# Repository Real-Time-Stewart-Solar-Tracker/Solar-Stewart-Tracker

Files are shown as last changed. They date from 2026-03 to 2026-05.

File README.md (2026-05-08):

# SunLock Lab Solar Stewart Tracker

<p align="center">
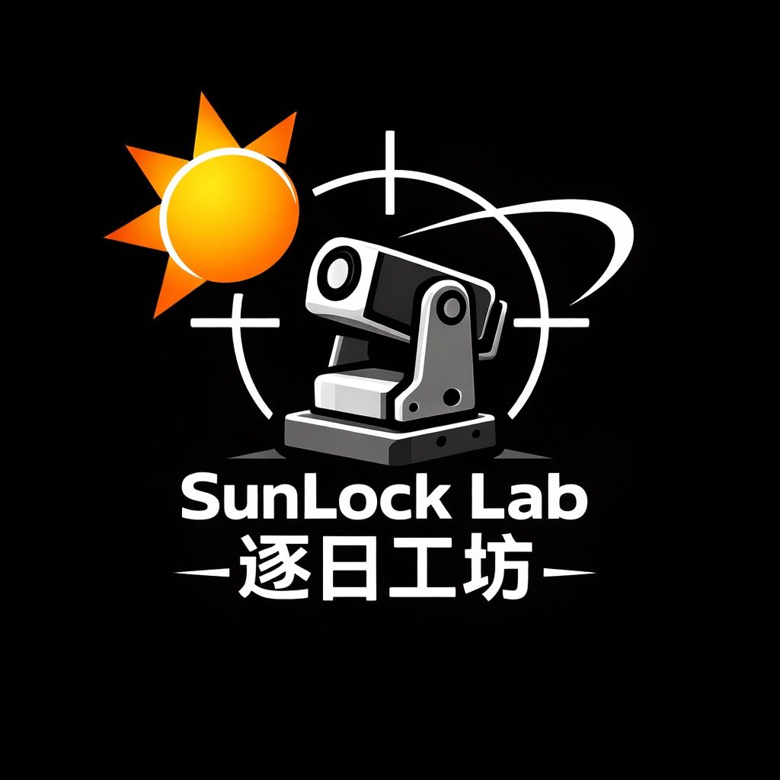
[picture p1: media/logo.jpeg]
SunLock Lab Solar Stewart Tracker
  
</p>





Real-time embedded **C++17** software for solar tracking using a **3-RRS Stewart-type parallel mechanism** on **Raspberry Pi / Linux**.

This project implements an event-driven pipeline in which camera frames are delivered through callbacks, processed by vision and control modules, converted into platform motion through inverse kinematics, and safely applied to three actuators through a hardware abstraction layer. The runtime is structured around blocking waits, callback-driven stage transitions, bounded queues, and modular components so the software remains responsive, maintainable, testable, and reproducible.

<p align="center">
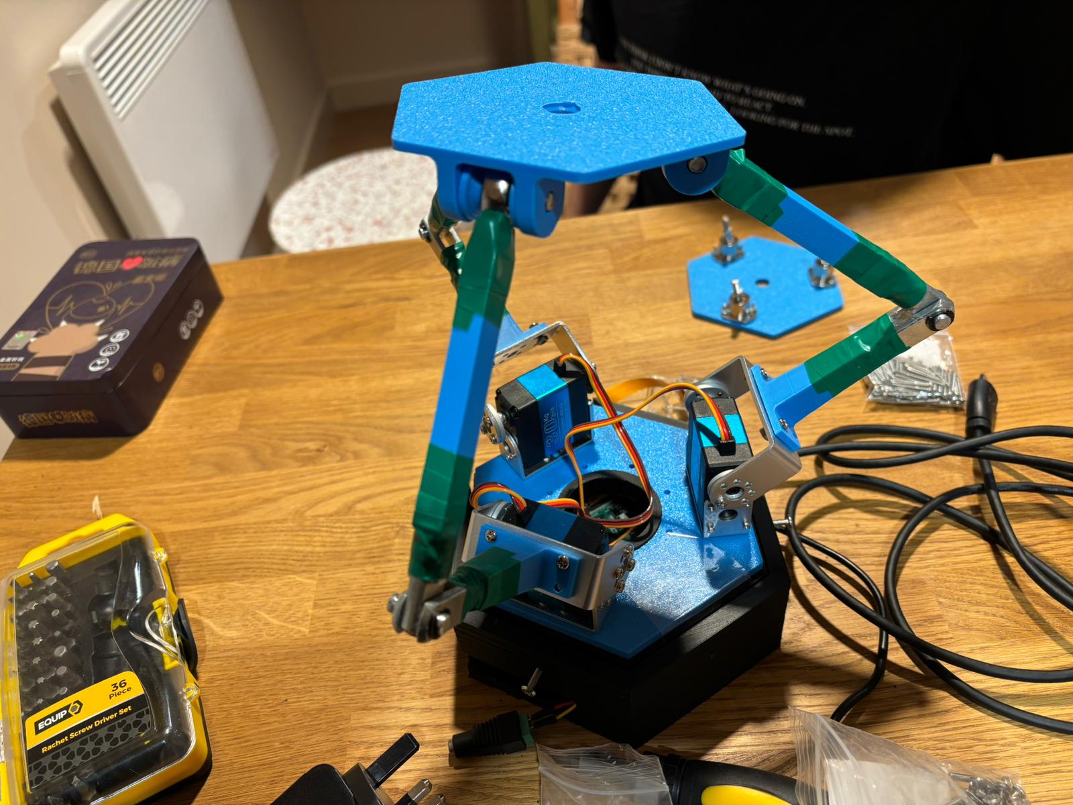
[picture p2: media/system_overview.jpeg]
System Overview
  
</p>
<p align="center">
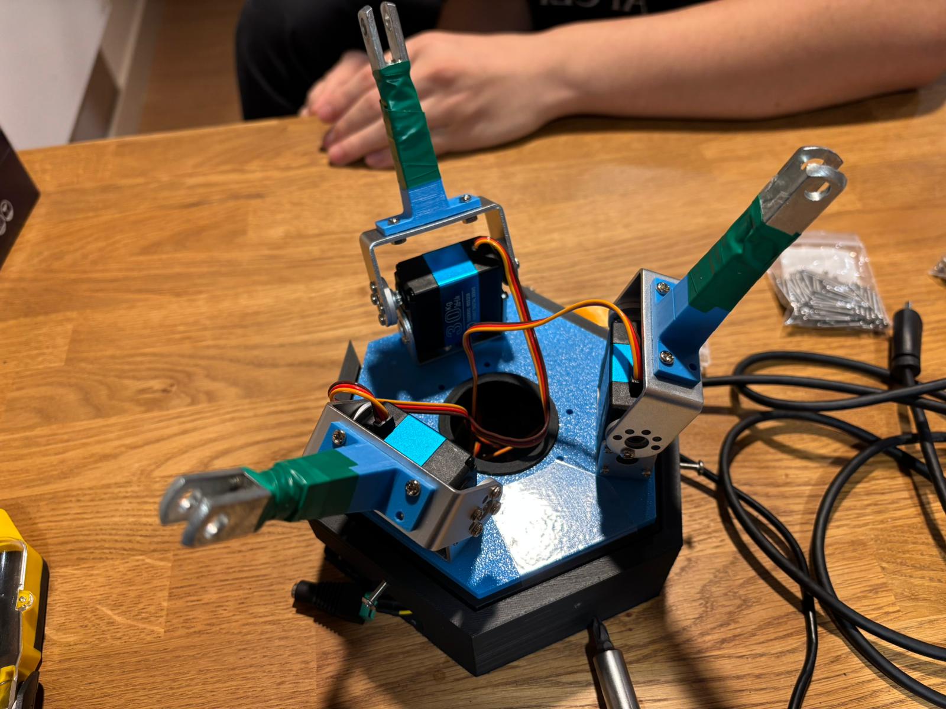
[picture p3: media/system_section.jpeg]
System Section
  
</p>
<p align="center">
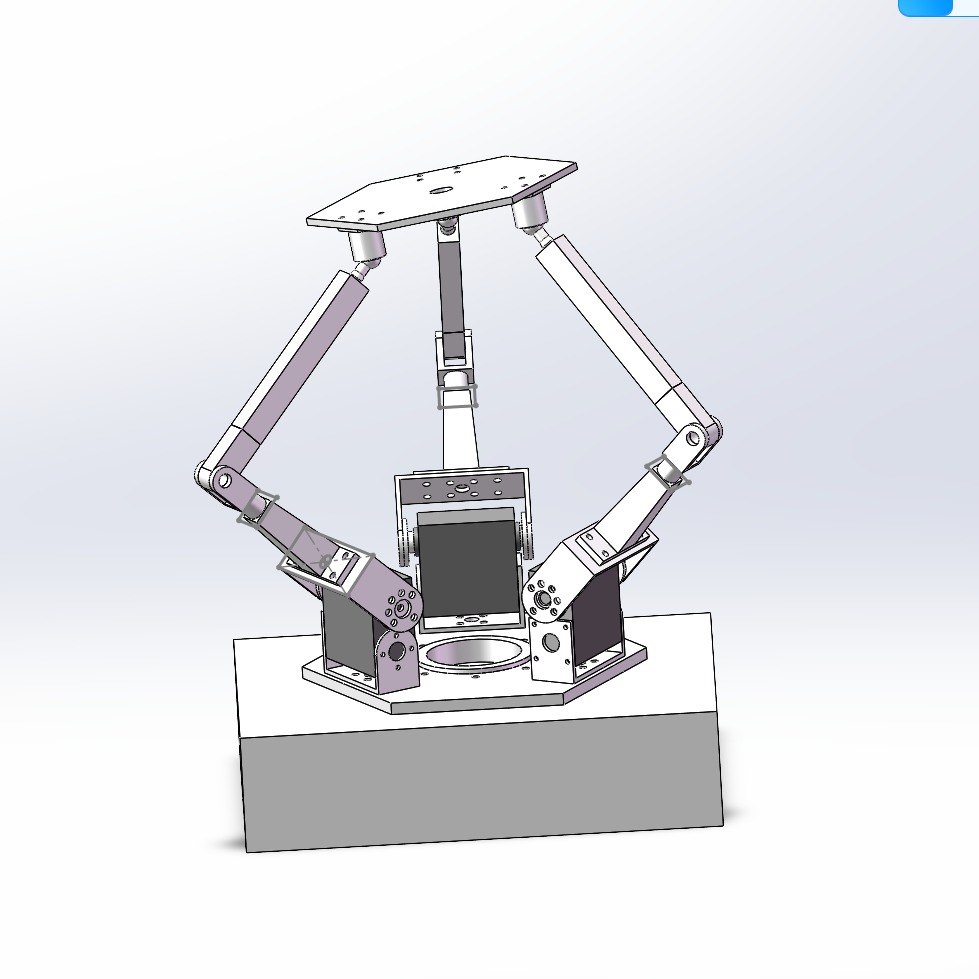
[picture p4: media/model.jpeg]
System Model
  
</p>

### Demo

A short demonstration of the tracker running on hardware is available in the repository root:
https://www.youtube.com/shorts/J-tgFS92vjE
[`Demo Solar Tracker.mp4`](Demo%20Solar%20Tracker.mp4)

---

<p align="center">
  <strong>Explore the full generated developer reference, architecture pages, and API documentation.</strong><br>
  📘 <a href="https://real-time-stewart-solar-tracker.github.io/Solar-Stewart-Tracker/">
    Doxygen Documentation
  </a>
</p>

---

## Table of Contents

- [Social Media](#social-media)
- [Project Overview](#project-overview)
- [Project Management](#project-management)
- [Key Features](#key-features)
- [System Architecture](#system-architecture)
- [Threading and Event Model](#threading-and-event-model)
- [Sequence Diagram](#sequence-diagram)
- [Circuit Diagram](#circuit-diagram)
- [Repository Structure](#repository-structure)
- [Bill of Materials](#bill-of-materials)
- [Dependencies](#dependencies)
- [Cloning](#cloning)
- [Building](#building)
- [Running](#running)
- [Running Tests](#running-tests)
- [Realtime Evidence](#realtime-evidence)
- [Documentation](#documentation)
- [Authors and Contributions](#authors-and-contributions)
- [Acknowledgements](#acknowledgements)
- [License](#license)
- [Future Work](#future-work)
- [Last Updated](#last-updated)

---

## Social Media

We actively document the development, testing, and realtime performance of the **Solar Stewart Tracker**.

The project is documented and published across the following platforms.

📌 **TikTok** — realtime tracking demos, hardware setup, and development clips\
https://www.tiktok.com/@sunlock.lab_2

📌 **Hackster.io** — full project write-up, hardware overview, and build guide\
https://www.hackster.io/fadihalteh21/real-time-solar-stewart-tracker-8ed4bb

Content includes:

- realtime tracking demonstrations
- hardware setup and wiring
- development progress updates
- testing and debugging clips

---

## Project Overview

The **Solar Stewart Tracker** is a Linux userspace realtime embedded system that:

- acquires camera frames from a camera backend
- detects the sun position using image processing
- computes tracking corrections
- converts desired motion into **3-RRS inverse kinematics**
- applies safety shaping before actuation
- drives three servo outputs through a PCA9685 PWM controller

The design goal is not only functional tracking, but tracking implemented in a way that is:

- **event-driven**
- **responsive**
- **modular**
- **testable**
- **reproducible**
- **safe for hardware control**

The main software path is:

**Camera → SunTracker → Controller → ManualImuCoordinator → Kinematics3RRS → ActuatorManager → ServoDriver**

For a detailed overview, see [docs/project_overview.md](docs/project_overview.md).

---

## Project Management

Development was organised through GitHub Milestones, Issues, Pull Requests, and tagged Releases:

- [Milestones](https://github.com/Real-Time-Stewart-Solar-Tracker/Solar-Stewart-Tracker/milestones?state=closed)
- [Issues](https://github.com/Real-Time-Stewart-Solar-Tracker/Solar-Stewart-Tracker/issues?q=is%3Aissue+state%3Aclosed)
- [Pull Requests](https://github.com/Real-Time-Stewart-Solar-Tracker/Solar-Stewart-Tracker/pulls?q=is%3Apr+is%3Aclosed)
- [Releases](https://github.com/Real-Time-Stewart-Solar-Tracker/Solar-Stewart-Tracker/releases)

---

## Key Features

- **Realtime event-driven processing**
  - callback-based frame delivery
  - blocking worker threads
  - no busy-wait control loop in the processing pipeline
  - no sleep-based timing in the control path

- **Modular C++17 architecture**
  - `SystemManager` orchestrates the runtime pipeline
  - hardware-facing and processing modules are separated by clear interfaces
  - optional backends and UI layers do not change the core architecture

- **Multiple build and use modes**
  - Linux / Raspberry Pi execution
  - software-only path with simulated camera input
  - headless CLI application
  - Qt GUI target

- **Safety-oriented actuation path**
  - actuator clamping
  - optional slew/rate limiting
  - neutral / park behaviour on start and stop
  - explicit handling of low-confidence tracking conditions
  - fault-driven suppression of invalid actuation commands

- **Engineering evidence built into the repository**
  - CMake-based build
  - CTest-integrated automated tests
  - latency measurement exported to artefacts
  - Doxygen-ready source tree
  - structured repository layout by subsystem

For class design rationale, see [docs/solid_justification.md](docs/solid_justification.md).
For requirements, see [docs/requirements.md](docs/requirements.md).

---

## System Architecture

<p align="center">
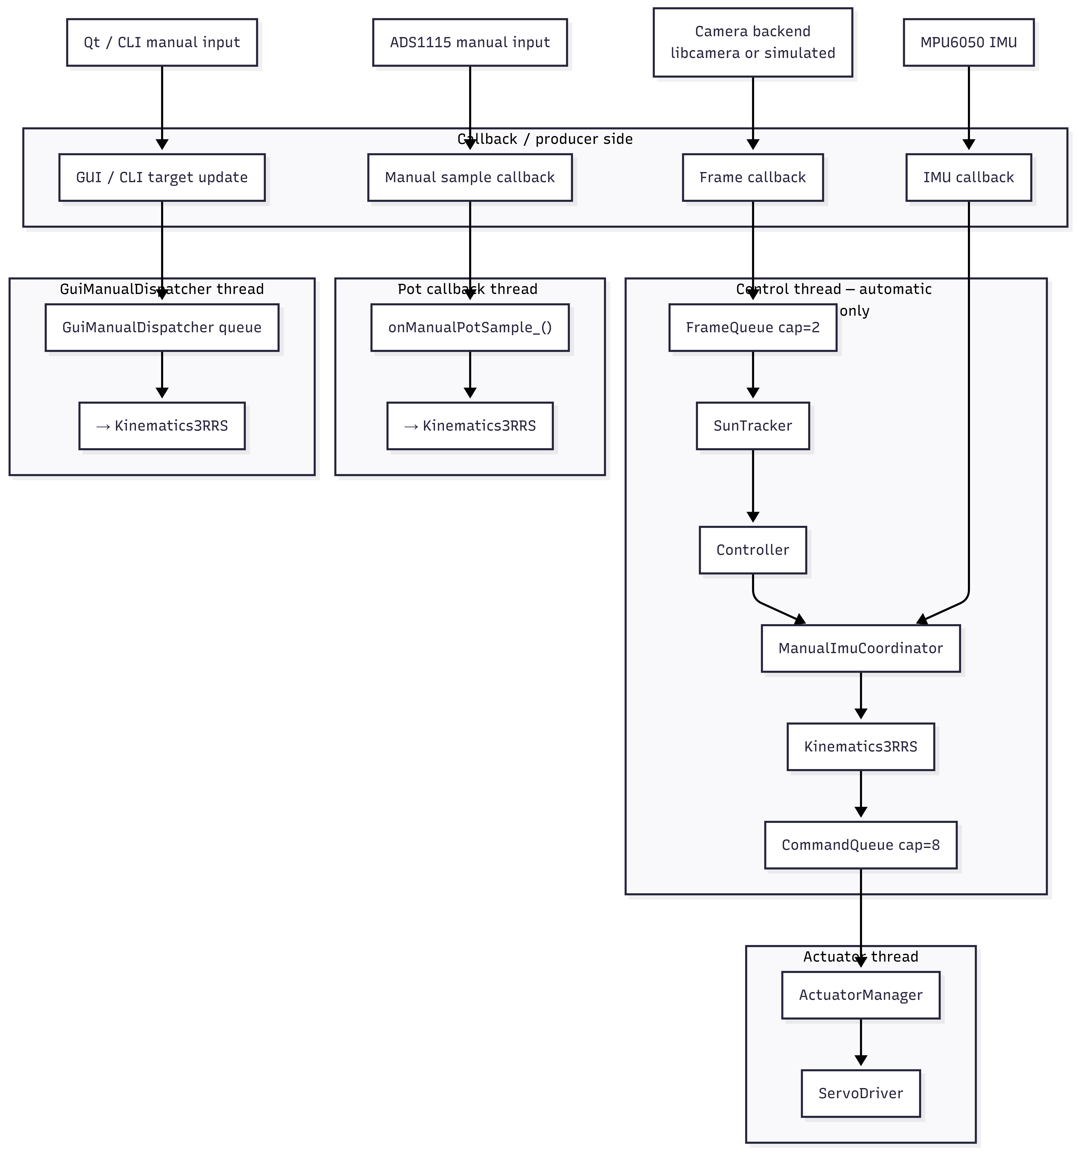
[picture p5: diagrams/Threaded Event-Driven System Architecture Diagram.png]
System Architecture
  
</p>

The repository is organised around a staged runtime pipeline.

### Core Modules

- **ICamera** — abstract camera interface used by the system.
- **LibcameraPublisher** — standalone direct libcamera backend implementing `ICamera`. Available as an alternative to the libcamera2opencv-based adapter assembled in `SystemFactory`.
- **SimulatedPublisher** — fallback or simulation camera backend.
- **SystemManager** — top-level orchestrator for state, queues, callbacks, and worker threads.
- **SunTracker** — vision module that finds the bright target and estimates sun position.
- **Controller** — converts tracking error into platform tilt/pan setpoints.
- **ManualImuCoordinator** — coordinates manual input ownership and optional IMU-based correction.
- **Kinematics3RRS** — converts platform setpoints into actuator-space commands.
- **ActuatorManager** — safety shaping layer for command limiting.
- **ServoDriver** — final actuator output layer.
- **LatencyMonitor** — measures timing across the userspace pipeline.

### Queue Policy

Inter-stage communication uses bounded queues with a freshest-data policy:

- **frame queue capacity:** 2
- **command queue capacity:** 8

Both queues use `push_latest(...)`. When a queue is full, the oldest item is discarded before the newest item is inserted. This bounds memory use, prevents unbounded backlog, and keeps the control path biased toward current data rather than stale queued work.

For detailed architecture, callback map, and blocking I/O map, see [docs/system_architecture.md](docs/system_architecture.md).
For the runtime state machine, see [docs/state_machine.md](docs/state_machine.md).

---

## Threading and Event Model

| Thread | Responsibility | Blocking Wakeup Source |
|---|---|---|
| Camera worker | Frame acquisition | timerfd + poll() (simulated) · libcamera callback (hardware) |
| Control worker | Vision + control (automatic only) | frame_q\_ condition_variable wait |
| Actuator worker | Safety conditioning + servo output | cmd_q\_ condition_variable wait |
| GuiManualDispatcher | GUI manual setpoint dispatch | GuiManualDispatcher queue condition_variable wait |
| ADS1115 GPIO callback | Pot sample read + dispatch | ALERT/RDY GPIO edge (libgpiod) |
| MPU6050 GPIO callback | IMU sample read + forward | Data-ready GPIO edge (libgpiod) |
| Main thread | App lifecycle, CLI, signals | poll() on signalfd / timerfd / stdin |

Every thread blocks on a blocking primitive (poll, condition_variable, or GPIO edge wait) and wakes only when an external event occurs. No thread uses polling loops or sleep-based timing anywhere in the codebase.

For the full callback map, blocking I/O map, and realtime execution model, see [docs/system_architecture.md](docs/system_architecture.md) and [docs/realtime_analysis.md](docs/realtime_analysis.md).

---

## Sequence Diagram

```mermaid
sequenceDiagram
    actor User
    participant Cam as Camera
    participant SM as SystemManager
    participant BC as BackendCoordinator
    participant GMD as GuiManualDispatcher
    participant FQ as FrameQueue
    participant CT as Control thread
    participant ST as SunTracker
    participant C as Controller
    participant MIC as ManualImuCoordinator
    participant K as Kinematics3RRS
    participant CQ as CommandQueue
    participant AT as Actuator thread
    participant AM as ActuatorManager
    participant SD as ServoDriver
    participant ADS as ADS1115
    participant IMU as MPU6050
    participant LM as LatencyMonitor

    User->>SM: start()
    SM->>SD: start()
    SM->>GMD: start()
    SM->>BC: start()
    Note over BC: starts ADS1115 and IMU backends
    SM->>Cam: start()
    SM->>SM: state = SEARCHING / MANUAL

    IMU-->>SM: imu sample callback
    SM->>MIC: updateImuSample(sample)

    rect rgb(245,245,255)
    Note over Cam,SD: Automatic path — control thread only
    Cam-->>SM: FrameEvent callback
    SM->>LM: onCapture(...)
    SM->>FQ: push_latest(frame)

    CT->>FQ: wait_pop()
    FQ-->>CT: FrameEvent
    CT->>ST: onFrame(frame)
    ST-->>CT: SunEstimate callback
    CT->>LM: onEstimate(...)
    CT->>C: onEstimate(estimate)
    C-->>CT: PlatformSetpoint callback
    CT->>LM: onControl(...)
    CT->>MIC: applyImuCorrection(setpoint)
    MIC-->>CT: corrected setpoint
    CT->>K: onSetpoint(setpoint)
    K-->>CT: ActuatorCommand callback
    CT->>CQ: push_latest(command)
    end

    rect rgb(245,255,245)
    Note over ADS,K: Pot manual path — ADS1115 callback thread, independent of camera frames
    ADS-->>SM: ManualPotSample callback
    SM->>MIC: buildManualSetpointFromPot(...)
    MIC-->>SM: PlatformSetpoint
    SM->>MIC: applyImuCorrection(sp)
    MIC-->>SM: corrected setpoint
    SM->>LM: onControl(...)
    SM->>K: onSetpoint(setpoint)
    K-->>SM: ActuatorCommand callback
    SM->>CQ: push_latest(command)
    end

    rect rgb(255,250,240)
    Note over User,K: GUI manual path — GuiManualDispatcher thread, independent of camera frames
    User->>SM: enterManual()
    SM->>SM: state = MANUAL

    User->>SM: setManualSetpoint(tilt, pan)
    SM->>GMD: setSetpoint(tilt, pan)
    Note over GMD: push_latest wakes thread immediately
    GMD->>MIC: buildManualSetpointFromGui(...)
    MIC-->>GMD: PlatformSetpoint
    GMD->>MIC: applyImuCorrection(sp)
    MIC-->>GMD: corrected setpoint
    GMD->>LM: onControl(...)
    GMD->>K: onSetpoint(setpoint)
    K-->>GMD: ActuatorCommand callback
    GMD->>CQ: push_latest(command)

    User->>SM: exitManual()
    SM->>SM: state = SEARCHING
    end

    rect rgb(240,240,240)
    Note over CQ,SD: Actuator path — actuator thread
    AT->>CQ: wait_pop()
    CQ-->>AT: ActuatorCommand
    AT->>AM: onCommand(command)
    AM-->>AT: safe command callback
    AT->>LM: onActuate(...)
    AT->>SD: apply(command)
    end

    User->>SM: stop()
    SM->>Cam: stop()
    SM->>BC: stop()
    SM->>GMD: stop()
    SM->>SD: stop()
    SM->>SM: state = IDLE
```

---

## Circuit Diagram

<p align="center">
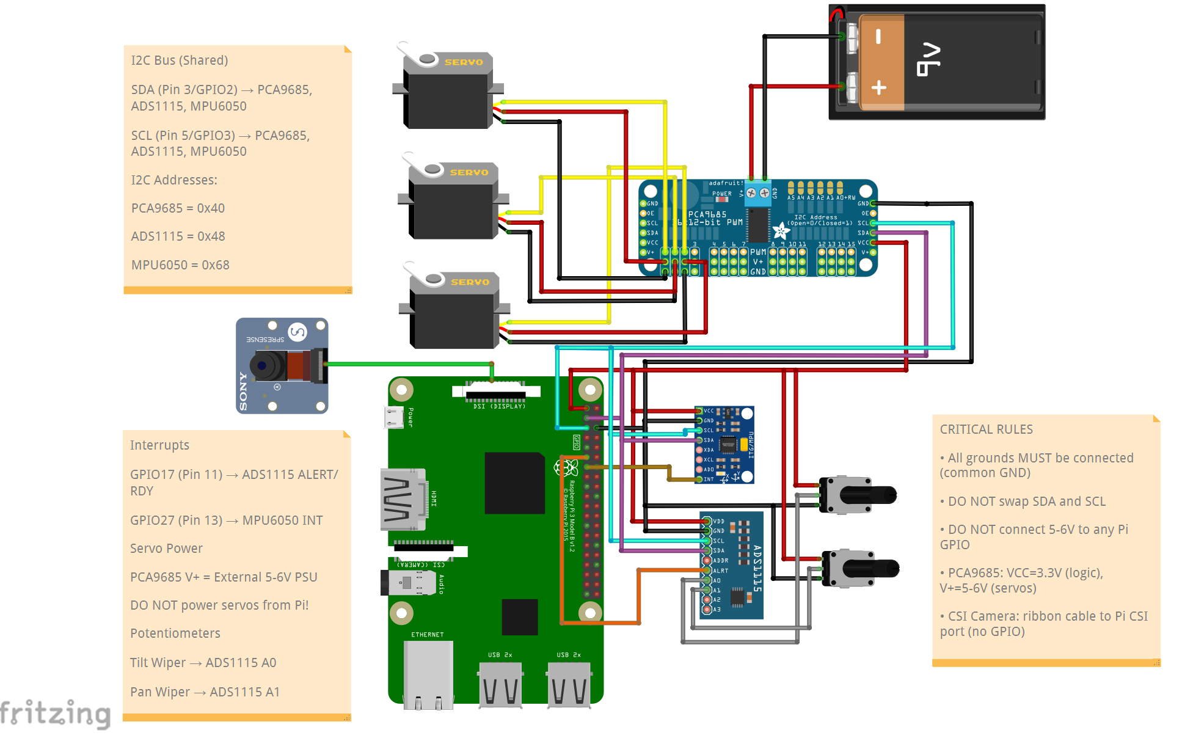
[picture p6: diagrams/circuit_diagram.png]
Circuit Diagram
  
</p>

The hardware setup connects:

- camera through a libcamera-compatible interface
- PCA9685 PWM driver over I2C
- ADS1115 over I2C for manual input
- MPU6050 over I2C for feedback
- three servo motors
- Raspberry Pi acting as the central controller

The PCA9685 generates PWM signals for the servos, while I2C provides communication between the Raspberry Pi, the manual-input ADC, the IMU, and the actuator driver layer.

For exact pin-level connections, see [docs/hardware_connections.md](docs/hardware_connections.md).
The editable Fritzing source file is available at [`diagrams/circuit_diagram.fzz`](diagrams/circuit_diagram.fzz).

---

## Repository Structure

```text
Solar-Stewart-Tracker/
├── .github/
│   └── workflows/
├── artefacts/
├── external/
│   ├── libcamera2opencv/
│   └── libgpiod_event_demo/
├── scripts/
├── src/
│   ├── actuators/
│   │   └── tests/
│   ├── app/
│   ├── common/
│   │   └── tests/
│   ├── control/
│   │   └── tests/
│   ├── hal/
│   │   └── tests/
│   ├── qt/
│   ├── sensors/
│   │   └── tests/
│   ├── system/
│   │   └── tests/
│   ├── tests/
│   │   └── support/
│   └── vision/
│       └── tests/
├── CMakeLists.txt
├── CONTRIBUTING.md
├── Doxyfile
└── LICENSE
```

---

## Bill of Materials

### Controller

| Component | Quantity | Cost (£) |
|---|---:|---:|
| Raspberry Pi 5 (8GB) | 1 | 80.00 |

### Sensors and Vision

| Component | Quantity | Cost (£) |
|---|---:|---:|
| IMX219 Camera Module | 1 | 25.00 |

### Actuation and Drive

| Component | Quantity | Cost (£) |
|---|---:|---:|
| PCA9685 PWM Driver | 1 | 12.00 |
| High-Torque Servo (RDS3230 or equivalent) | 3 | 45.00 |
| External 5–6V High-Current Supply | 1 | 20.00 |

### Mechanical and Supporting Components

| Component | Quantity | Cost (£) |
|---|---:|---:|
| Breadboard and Wiring Set | 1 | 10.00 |
| Structural Frame / 3D Printed Parts | 1 | 15.00 |
| Fasteners and Mounts | Assorted | 10.00 |

**Grand Total: £217.00**

For a detailed bill of materials, see [docs/BOM.md](docs/BOM.md).

---

## Dependencies

The following packages are required on Raspberry Pi OS (Debian Trixie, 64-bit):

```bash
sudo apt update
sudo apt install -y build-essential cmake git pkg-config ninja-build
sudo apt install -y libcamera-dev libopencv-dev libturbojpeg0-dev libgpiod-dev
sudo apt install -y qtbase5-dev qtcharts5-dev qt5-qmake
sudo apt install -y doxygen graphviz
```

For a complete dependency reference, see [docs/DEPENDENCIES.md](docs/DEPENDENCIES.md).

---

## Cloning

```bash
git clone --recurse-submodules https://github.com/Real-Time-Stewart-Solar-Tracker/Solar-Stewart-Tracker.git
cd Solar-Stewart-Tracker
```

If you already cloned without submodules:

```bash
git submodule update --init --recursive
```

> **Note:** The GitHub auto-generated source ZIP does not include submodule contents. Always clone with `--recurse-submodules`.

### Submodules

This project depends on two external submodules under `external/`:

- [`external/libcamera2opencv`](https://github.com/berndporr/libcamera2opencv) — libcamera to OpenCV bridge for the camera backend
- [`external/libgpiod_event_demo`](https://github.com/berndporr/libgpiod_event_demo) — event-driven GPIO wrapper for ADS1115 and MPU6050 interrupt handling

Both are required for a successful build. If either directory is empty after cloning, run `git submodule update --init --recursive`.

---

## Building

```bash
cmake -S . -B build -G Ninja -DCMAKE_BUILD_TYPE=Release
cmake --build build -j
```

This builds all targets including the CLI application, the Qt GUI, and all tests. No hardware needs to be connected — only the development libraries installed via `apt`.

---

## Running

### Headless CLI

```bash
./build/solar_tracker
```

### Qt GUI (full application with live preview and manual controls)

```bash
./build/src/qt/solar_tracker_qt
```

### Hardware Mode

Hardware execution requires:

- libcamera-compatible camera connected
- I2C enabled on the host
- PCA9685 and servos connected and powered
- external 5–6V servo power supply

The system enters `FAULT` if required hardware is unavailable at startup.

### Runtime Latency Capture

```bash
mkdir -p artefacts
SOLAR_LATENCY_CSV=artefacts/latency.csv ./build/solar_tracker
```

Type `quit` and press Enter to stop cleanly. Latency data is written to `artefacts/latency.csv` on shutdown.

For reproducibility steps and environment setup, see [docs/REPRODUCIBILITY.md](docs/REPRODUCIBILITY.md).

---

## Running Tests

```bash
ctest --test-dir build --output-on-failure
```

Or via the convenience script:

```bash
./scripts/test_core.sh
```

### Included Automated Test Areas

- SunTracker
- Controller
- ManualInputMapper
- ImuFeedbackMapper
- ImuTiltEstimator
- ActuatorManager
- ThreadSafeQueue
- Kinematics3RRS
- LatencyMonitor
- SystemManager state handling
- PCA9685
- ServoDriver
- MPU6050 publisher
- Linux I2C hardware smoke path

For the full testing strategy and test matrix, see [docs/testing.md](docs/testing.md).

---

## Realtime Evidence

Latency was measured on real hardware using the **libcamera2opencv** backend (IMX219 CSI sensor, 640×480, RGB888, 30 fps) on a Raspberry Pi 5. Frame-interval analysis (standard deviation 4.46 ms) confirms the measurements reflect genuine camera sensor timing, not synthetic simulation.

The measured software-side pipeline is:

**Camera → FrameQueue → SunTracker → Controller → ManualImuCoordinator → Kinematics3RRS → ActuatorManager → ServoDriver**

All measurements are taken using monotonic timestamps recorded inside the software pipeline and exported to `artefacts/latency.csv`.

### Latency Results (1367 frames, 46.6 seconds)

| Metric | Average (ms) | Minimum (ms) | Maximum (ms) | Jitter (ms) |
|---|---:|---:|---:|---:|
| L_total | 2.397656 | 1.869860 | 4.553350 | 2.683490 |
| L_vision | 2.379005 | 1.859520 | 4.531040 | 2.671520 |
| L_control | 0.001495 | 0.000500 | 0.070347 | 0.069847 |
| L_actuation | 0.017155 | 0.008648 | 0.156285 | 0.147637 |

### Interpretation

- average end-to-end software latency is approximately **2.40 ms**
- worst-case measured software latency is approximately **4.55 ms**
- processing uses approximately **7.3%** of a 30 Hz frame period (33 ms)
- measurements represent the userspace software path only, not full physical actuator motion or mechanical settling time

For detailed latency analysis, design decisions informed by measurements, and frame-interval evidence, see [docs/latency_measurement.md](docs/latency_measurement.md).
For the realtime execution model and event-driven architecture, see [docs/realtime_analysis.md](docs/realtime_analysis.md).

---

## Documentation

### Doxygen API Reference

The generated developer reference is hosted online:

https://real-time-stewart-solar-tracker.github.io/Solar-Stewart-Tracker/

To generate locally:

```bash
doxygen Doxyfile
```

Open at `docs/html/index.html`.

### Source Areas Covered

- `src/actuators`
- `src/app`
- `src/common`
- `src/control`
- `src/hal`
- `src/sensors`
- `src/system`
- `src/vision`
- `src/qt`

### Project Documentation

| Document | Description |
|---|---|
| [docs/project_overview.md](docs/project_overview.md) | Project summary |
| [docs/system_architecture.md](docs/system_architecture.md) | Architecture, callback map, blocking I/O map |
| [docs/state_machine.md](docs/state_machine.md) | Runtime state machine |
| [docs/realtime_analysis.md](docs/realtime_analysis.md) | Realtime execution model |
| [docs/latency_measurement.md](docs/latency_measurement.md) | Quantitative latency evidence |
| [docs/testing.md](docs/testing.md) | Testing strategy and test matrix |
| [docs/solid_justification.md](docs/solid_justification.md) | SOLID class design rationale |
| [docs/requirements.md](docs/requirements.md) | Functional and non-functional requirements |
| [docs/user_stories_use_cases.md](docs/user_stories_use_cases.md) | User stories and use cases |
| [docs/DEPENDENCIES.md](docs/DEPENDENCIES.md) | Dependency reference |
| [docs/REPRODUCIBILITY.md](docs/REPRODUCIBILITY.md) | Reproducibility guide |
| [docs/build_and_run.md](docs/build_and_run.md) | Build and run reference |
| [docs/hardware_connections.md](docs/hardware_connections.md) | Pin-level wiring reference |
| [docs/BOM.md](docs/BOM.md) | Bill of materials |

---

## Authors and Contributions

**Fadi Halteh (3127931H)**
Designed and implemented the event-driven system architecture, including runtime orchestration, state handling, and the bounded queue pipeline. Responsible for integrating the major software stages into the full runtime path. Implemented the MPU6050 (IMU) and ADS1115 (manual input) integration within the system, including their event-driven data handling and coordination with the control pipeline. Also responsible for the system architecture design and creation of the technical diagrams (pipeline, threading, and system architecture).

**Jichao Wang (3137140W)**
Led the project’s early technical development by building the 3-RRS inverse kinematics model and simulation workflow in MATLAB, and by exporting the resulting actuator control commands to STM32 for feasibility validation on embedded hardware. He later developed a complete Raspberry Pi-based Python tracking system, including YOLO-based visual target detection, PID control, an inverse kinematics algorithm aligned with the MATLAB prototype, and PCA9685-based servo actuation, which laid the groundwork for the later transition to the C++ version. In addition, he designed the SolidWorks mechanical model, carried out the 3D printing of key structural parts, handled component and motor selection and procurement, developed an MPU6050-based control scheme for servo input testing, and contributed to project presentation materials by editing the team’s first TikTok video.

**Ziming Yan (2429452Y)**
Developed the vision subsystem and user interface components, including the SunTracker detection pipeline and Qt-based control panel. Integrated visual feedback, overlays, and runtime interaction into the system.

**Tareq A M Almzanin (3139787A)**
Implemented the control layer translating vision estimates into platform motion, including closed-loop control logic and manual override behaviour. Contributed to the definition of shared data types and the control-side software path.

**Zhenyu Zhu (3099498Z)**
Implemented the low-level actuator interface including PCA9685 integration and servo control, along with latency measurement instrumentation. Responsible for hardware abstraction and timing analysis across the system pipeline.

---

## Acknowledgements

We would like to thank:

- Dr. Bernd Porr for guidance in realtime embedded systems and architecture design
- Dr. Chongfeng Wei for software engineering support and project supervision
- the University of Glasgow
- the laboratory, workshop, and technical support staff involved in supporting the project

Their guidance and infrastructure helped shape both the realtime architecture and the engineering process behind this repository.

---

## License

This project is released under the [MIT License](LICENSE).

### External Components and Attribution

The repository also includes or depends on external open-source components. Please credit and use them according to their original licenses.

- **libcamera2opencv** — https://github.com/berndporr/libcamera2opencv
- **libgpiod_event_demo** — https://github.com/berndporr/libgpiod_event_demo

---

## Future Work

Planned or natural next extensions include:

- richer telemetry and live plotting
- enhanced fault handling and recovery strategies
- broader hardware-backed integration testing
- further public-facing project media and demonstration material

---

## Last Updated

April 2026

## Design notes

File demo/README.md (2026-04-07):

# Pipeline Demo

Demonstrates the full automatic tracking pipeline **without any hardware**.

## What it shows

```
SimulatedPublisher → SunTracker → Controller → Kinematics3RRS → stdout
```

A synthetic camera generates 640×480 frames at 30 fps with a bright spot that moves
slowly around the image.  Each stage processes the events in turn and the demo prints
one line per frame showing:

- the detected sun position (pixels) and confidence
- the computed tilt/pan setpoint (radians)
- the resulting servo angles for all 3 actuators (degrees)

## Expected output

```
=== Solar Stewart Tracker — Pipeline Demo ===
Running simulated pipeline for 5 seconds...

[frame    1] sun=( 320.0,  240.0) conf=1.00  →  tilt=+0.000 rad  pan=+0.000 rad  →  servos=[ 90.0,  90.0,  90.0]  status=OK
[frame    2] sun=( 323.1,  241.2) conf=1.00  →  tilt=-0.003 rad  pan=+0.005 rad  →  servos=[ 89.9,  89.8,  90.1]  status=OK
...

=== Demo complete ===
Total frames processed: 150
```

## Requirements

- Same build toolchain as the main project (CMake ≥ 3.16, GCC/Clang with C++17)
- No camera, no I²C, no servos needed

## Build

From the repository root:

```bash
cmake -B build -DCMAKE_BUILD_TYPE=Release
cmake --build build --target pipeline_demo
```

Or add `add_subdirectory(demo)` to the root `CMakeLists.txt`
and rebuild normally.

## Run

```bash
./build/demo/pipeline_demo
```

The demo runs for 5 seconds and exits automatically.

## What to look for

| What you see | What it means |
|---|---|
| `conf=0.00` for the first few frames | The spot starts at centre — zero error, zero confidence needed |
| `tilt`/`pan` grow as the spot moves off-centre | The controller is reacting to the image error |
| `servos` values changing | Kinematics is solving the inverse-kinematics in real time |
| `status=DEGRADED` (if it appears) | The IK solver hit a geometry limit and fell back to the last valid command |

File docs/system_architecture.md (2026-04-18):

# System Architecture

## Overview

The system is structured as a staged, event-driven pipeline in Linux userspace. Frame acquisition, tracking, control, kinematic mapping, and actuator output are separated into distinct classes so that each stage has a clear responsibility and a bounded interface. This is consistent with the taught architecture of sensor events propagating through callbacks and typed data transformations to control outputs.

The implemented automatic processing path is:

**ICamera → SunTracker → Controller → ManualImuCoordinator → Kinematics3RRS → ActuatorManager → ServoDriver**

`SystemManager` orchestrates this pipeline and manages runtime state. `BackendCoordinator` owns hardware backend lifecycle. `GuiManualDispatcher` provides the event-driven GUI manual path. `SystemFactory` assembles the runtime graph.

This class structure is stronger than a monolithic alternative because it separates:

- sensor acquisition from estimation
- estimation from control
- control from mechanism-specific mapping
- mechanism mapping from actuator safety conditioning
- actuator conditioning from final hardware output
- runtime orchestration from backend implementation details

That separation improves maintainability, reduces coupling, and makes the realtime event flow explicit.

---

## Architectural Rationale

The core design decision is to preserve a forward-only event path through specialised classes instead of building one large tracker class. In this repository, each stage transforms one well-defined form of data into the next.

For automatic tracking:

- the camera backend emits frames
- the tracker estimates target position and confidence
- the controller converts that estimate into a platform command
- the manual/IMU coordination layer applies optional correction
- the kinematics layer maps platform motion into actuator-space commands
- the actuator manager applies command conditioning and output safety policy
- the servo driver performs final calibrated output to the physical device

For manual mode, both input paths are independently event-driven:

**Pot-driven manual:** ADS1115 ALERT/RDY GPIO edge → `onManualPotSample_()` → setpoint built and dispatched directly to `Kinematics3RRS`. Timing is driven by the ADS1115 conversion rate, independent of camera frames.

**GUI-driven manual:** Qt slider → `setManualSetpoint()` → `GuiManualDispatcher::setSetpoint()` → push to bounded queue → `GuiManualDispatcher` worker thread wakes immediately → setpoint built via `ManualImuCoordinator` and dispatched directly to `Kinematics3RRS`. Timing is driven by operator input rate, independent of camera frames.

The control thread handles only the automatic path. It is not involved in either manual path.

This staged structure is appropriate because the taught approach is event-driven userspace code built around callbacks, blocking waits, and clean class interfaces rather than polling loops or single-threaded delay-based control.

---
## Callback Map

| Publisher | Subscriber | Callback Type | Registration Method |
|---|---|---|---|
| ICamera | SystemManager | std::function\<void(const FrameEvent&)\> | registerFrameCallback() |
| SunTracker | SystemManager | std::function\<void(const SunEstimate&)\> | registerEstimateCallback() |
| Controller | SystemManager | std::function\<void(const PlatformSetpoint&)\> | registerSetpointCallback() |
| Kinematics3RRS | SystemManager | std::function\<void(const ActuatorCommand&)\> | registerCommandCallback() |
| ActuatorManager | SystemManager | std::function\<void(const ActuatorCommand&)\> | registerSafeCommandCallback() |
| IIMU | BackendCoordinator | abstract CallbackInterface::hasSample() | registerEventCallback() |
| ADS1115ManualInput | BackendCoordinator | std::function\<void(const ManualPotSample&)\> | registerCallback() |
| LatencyMonitor | SystemManager | std::function\<void(...)\> | registerObserver() |

Inter-class communication uses callbacks (not getters) for incoming events and setters for outgoing control, consistent with the taught event-driven architecture.
---

## Threading and Blocking I/O Map

| Thread | Responsibility | Blocking Wakeup Source |
|---|---|---|
| Camera worker | Frame acquisition | timerfd + poll() (simulated) · libcamera callback (hardware) |
| Control worker | Vision + control (automatic only) | frame_q\_ condition_variable wait |
| Actuator worker | Safety conditioning + servo output | cmd_q\_ condition_variable wait |
| GuiManualDispatcher | GUI manual setpoint dispatch | GuiManualDispatcher queue condition_variable wait |
| ADS1115 GPIO callback | Pot sample read + dispatch | ALERT/RDY GPIO edge (libgpiod) |
| MPU6050 GPIO callback | IMU sample read + forward | Data-ready GPIO edge (libgpiod) |
| Main thread | App lifecycle, CLI, signals | poll() on signalfd / timerfd / stdin |

Every thread blocks on a kernel-backed primitive and wakes only when an external event occurs. No thread uses polling loops or sleep-based timing anywhere in the codebase.

---

## Diagram 1 — UML Class Diagram

```mermaid
classDiagram
direction LR

class SystemManager {
  +start() bool
  +stop() void
  +state() TrackerState
  +enterManual() void
  +exitManual() void
  +setManualSetpoint(tilt_rad, pan_rad) void
  +setTrackerThreshold(thr) void
  +setManualCommandSource(src) void
  +registerFrameObserver(cb) void
  +registerEstimateObserver(cb) void
  +registerSetpointObserver(cb) void
  +registerCommandObserver(cb) void
  +registerLatencyObserver(cb) void
  -onFrame_(fe) void
  -controlLoop_() void
  -actuatorLoop_() void
  -setState_(s) void
  -applyNeutralOnce_() void
  -applyParkOnce_(servo_deg) void
}

class BackendCoordinator {
  +start(log) StartResult
  +stop() void
}

class GuiManualDispatcher {
  +start() void
  +stop() void
  +setSetpoint(tilt_rad, pan_rad) void
  +registerSetpointObserver(cb) void
}

class ICamera {
  <<interface>>
  +registerFrameCallback(cb) void
  +start() bool
  +stop() void
  +isRunning() bool
}

class LibcameraPublisher
class SimulatedPublisher
ICamera <|.. LibcameraPublisher
ICamera <|.. SimulatedPublisher

class ThreadSafeQueue~T~ {
  +ThreadSafeQueue(capacity)
  +wait_pop() optional~T~
  +push_latest(item) bool
  +stop() void
  +reset() void
  +clear() void
}

class SunTracker {
  +registerEstimateCallback(cb) void
  +setThreshold(thr) void
  +onFrame(fe) void
}

class Controller {
  +registerSetpointCallback(cb) void
  +onEstimate(est) void
}

class Kinematics3RRS {
  +registerCommandCallback(cb) void
  +onSetpoint(sp) void
}

class ActuatorManager {
  +registerSafeCommandCallback(cb) void
  +onCommand(cmd) void
}

class ServoDriver {
  +start() bool
  +stop() void
  +apply(cmd) void
}

class LatencyMonitor {
  +onCapture(frame_id, t) void
  +onEstimate(frame_id, t) void
  +onControl(frame_id, t) void
  +onActuate(frame_id, t) void
}

class ManualImuCoordinator {
  +setManualCommandSource(src) void
  +manualCommandSource() ManualCommandSource
  +updateImuSample(sample) void
  +applyImuCorrection(sp) PlatformSetpoint
  +buildManualSetpointFromPot(sample, state, frame_id, t, sp) bool
  +buildManualSetpointFromGui(tilt, pan, state, frame_id, t, sp) bool
}

class ADS1115ManualInput {
  +registerCallback(cb) void
  +start() bool
  +stop() void
}

class Mpu6050Publisher {
  +registerEventCallback(cb) void
  +start() bool
  +stop() void
}

SystemManager o-- ICamera
SystemManager o-- SunTracker
SystemManager o-- Controller
SystemManager o-- Kinematics3RRS
SystemManager o-- ActuatorManager
SystemManager o-- ServoDriver
SystemManager o-- LatencyMonitor
SystemManager o-- ManualImuCoordinator
SystemManager o-- BackendCoordinator
SystemManager o-- GuiManualDispatcher
BackendCoordinator o-- ADS1115ManualInput
SystemManager o-- Mpu6050Publisher

SystemManager o-- ThreadSafeQueue~FrameEvent~ : frame_q_ cap=2
SystemManager o-- ThreadSafeQueue~ActuatorCommand~ : cmd_q_ cap=8

ICamera ..> FrameEvent : emits via callback
SunTracker ..> SunEstimate : emits via callback
Controller ..> PlatformSetpoint : emits via callback
Kinematics3RRS ..> ActuatorCommand : emits via callback
ActuatorManager ..> ActuatorCommand : emits safe callback
ADS1115ManualInput ..> ManualPotSample : emits via callback
Mpu6050Publisher ..> ImuSample : emits via callback
ManualImuCoordinator ..> PlatformSetpoint : adjusts / builds
```

---

## Diagram 2.1 — Sequence Diagram — Automatic Runtime Pipeline

```mermaid
sequenceDiagram
autonumber

participant Cam as Camera backend
participant SM as SystemManager
participant FQ as FrameQueue cap=2
participant CT as Control thread
participant ST as SunTracker
participant C as Controller
participant MIC as ManualImuCoordinator
participant K as Kinematics3RRS
participant CQ as CommandQueue cap=8
participant AT as Actuator thread
participant AM as ActuatorManager
participant SD as ServoDriver
participant LM as LatencyMonitor

SM->>Cam: registerFrameCallback(onFrame_)
SM->>ST: registerEstimateCallback(...)
SM->>C: registerSetpointCallback(...)
SM->>K: registerCommandCallback(...)
SM->>AM: registerSafeCommandCallback(...)
SM->>SD: start()
SM->>Cam: start()
SM->>SM: setState(SEARCHING)

Cam-->>SM: FrameCallback(FrameEvent)
SM->>LM: onCapture(frame_id, t_capture)
SM->>FQ: push_latest(FrameEvent)

CT->>FQ: wait_pop()
FQ-->>CT: FrameEvent
CT->>ST: onFrame(FrameEvent)

ST-->>CT: EstimateCallback(SunEstimate)
CT->>LM: onEstimate(frame_id, t_estimate)

alt confidence >= threshold
  CT->>SM: setState(TRACKING)
else confidence < threshold
  CT->>SM: setState(SEARCHING)
end

CT->>C: onEstimate(SunEstimate)
C-->>CT: SetpointCallback(PlatformSetpoint)
CT->>LM: onControl(frame_id, t_control)

CT->>MIC: applyImuCorrection(PlatformSetpoint)
MIC-->>CT: corrected PlatformSetpoint

CT->>K: onSetpoint(corrected PlatformSetpoint)
K-->>CT: CommandCallback(ActuatorCommand)
CT->>CQ: push_latest(ActuatorCommand)

AT->>CQ: wait_pop()
CQ-->>AT: ActuatorCommand
AT->>AM: onCommand(ActuatorCommand)

AM-->>AT: SafeCommandCallback(ActuatorCommand)
AT->>LM: onActuate(frame_id, t_actuate)
AT->>SD: apply(ActuatorCommand)
```

---

## Diagram 2.2 — Sequence Diagram — Manual Input + IMU Update Paths

```mermaid
sequenceDiagram
autonumber

participant ADS as ADS1115ManualInput
participant IMU as Mpu6050Publisher
participant User as Qt / CLI User
participant SM as SystemManager
participant BC as BackendCoordinator
participant GMD as GuiManualDispatcher
participant MIC as ManualImuCoordinator
participant K as Kinematics3RRS
participant CQ as CommandQueue cap=8
participant AT as Actuator thread
participant AM as ActuatorManager
participant SD as ServoDriver
participant LM as LatencyMonitor

Note over BC,ADS: BackendCoordinator owns ADS1115 and IMU lifecycle
BC->>ADS: start()
BC->>IMU: start()

IMU-->>SM: IMU callback(sample)
SM->>MIC: updateImuSample(sample)

User->>SM: enterManual()
SM->>MIC: setManualCommandSource(Pot or GUI)
SM->>SM: setState(MANUAL)

alt Pot-controlled manual mode — ADS1115 ALERT/RDY edge driven
  ADS-->>SM: ManualPotSample callback
  SM->>MIC: buildManualSetpointFromPot(sample, state, id, t, sp)
  MIC-->>SM: PlatformSetpoint
  SM->>MIC: applyImuCorrection(sp)
  MIC-->>SM: corrected PlatformSetpoint
  SM->>LM: onControl(frame_id, t_control)
  SM->>K: onSetpoint(corrected PlatformSetpoint)
  Note over SM,K: Dispatched directly in ADS1115 callback — no frame dependency
else GUI-controlled manual mode — operator input rate driven
  User->>SM: setManualSetpoint(tilt, pan)
  SM->>GMD: setSetpoint(tilt, pan)
  Note over GMD: push_latest to bounded queue — wakes immediately
  GMD->>MIC: buildManualSetpointFromGui(tilt, pan, state, id, t, sp)
  MIC-->>GMD: PlatformSetpoint
  GMD->>MIC: applyImuCorrection(sp)
  MIC-->>GMD: corrected PlatformSetpoint
  GMD->>LM: onControl(frame_id, t_control)
  GMD->>K: onSetpoint(corrected PlatformSetpoint)
  Note over GMD,K: Dispatched from GuiManualDispatcher thread — no frame dependency
end

K-->>K: CommandCallback(ActuatorCommand)
K->>CQ: push_latest(ActuatorCommand)

AT->>CQ: wait_pop()
CQ-->>AT: ActuatorCommand
AT->>AM: onCommand(ActuatorCommand)
AM-->>AT: SafeCommandCallback(ActuatorCommand)
AT->>LM: onActuate(frame_id, t_actuate)
AT->>SD: apply(ActuatorCommand)

User->>SM: exitManual()
SM->>SM: setState(SEARCHING)
```

---

## Diagram 3 — Component Diagram

```mermaid
flowchart LR
  subgraph EntryPoints["Entry Points"]
    CLI["solar_tracker (CLI)"]
    QT["solar_tracker_qt (Qt UI)"]
  end

  subgraph Core["Core Realtime Pipeline"]
    SM["SystemManager"]
    FQ["FrameQueue cap=2<br/>ThreadSafeQueue&lt;FrameEvent&gt;"]
    CQ["CommandQueue cap=8<br/>ThreadSafeQueue&lt;ActuatorCommand&gt;"]
    ST["SunTracker"]
    C["Controller"]
    MIC["ManualImuCoordinator"]
    K["Kinematics3RRS"]
    AM["ActuatorManager"]
    SD["ServoDriver"]
    LM["LatencyMonitor"]
  end

  subgraph Vision["Camera Backends"]
    ICam["ICamera"]
    Lib["LibcameraPublisher"]
    Sim["SimulatedPublisher"]
  end

  subgraph ManualInput["Manual Input"]
    ADS["ADS1115ManualInput<br/>ALERT/RDY GPIO edge"]
    GMD["GuiManualDispatcher<br/>dedicated thread + queue"]
    BC["BackendCoordinator<br/>owns ADS1115 + IMU"]
  end

  subgraph ImuFeedback["IMU Feedback"]
    MPU["Mpu6050Publisher"]
  end

  CLI --> SM
  QT --> SM

  Lib -- implements --> ICam
  Sim -- implements --> ICam
  ICam -->|Frame callback| SM

  SM --> FQ
  FQ -->|wait_pop in control thread| ST
  ST --> C
  C --> MIC
  MIC --> K
  K --> CQ
  CQ -->|wait_pop in actuator thread| AM
  AM --> SD

  ADS -->|manual sample callback| SM
  SM -->|dispatch direct to K| K
  QT -->|setManualSetpoint| SM
  SM -->|setSetpoint| GMD
  GMD -->|dispatch direct to K| K
  MPU -->|IMU callback| SM
  SM --> MIC

  SM --> LM
```

---

## Diagram 4 — Threaded Event Architecture

```mermaid
flowchart TB
  CAM["Camera backend<br/>libcamera or simulated"]
  ADS["ADS1115 manual input"]
  MPU["MPU6050 IMU"]
  UI["Qt / CLI manual input"]

  subgraph T1["Callback / producer side"]
    CAMCB["Frame callback"]
    ADSCB["Manual sample callback"]
    MPUCB["IMU callback"]
    UICB["GUI / CLI target update"]
  end

  subgraph T2["Control thread — automatic path only"]
    FQ["FrameQueue cap=2"]
    ST["SunTracker"]
    CTRL["Controller"]
    MIC["ManualImuCoordinator"]
    KIN["Kinematics3RRS"]
    CQ["CommandQueue cap=8"]
  end

  subgraph T4["Pot callback thread (ADS1115)"]
    ADSCB2["onManualPotSample_()"]
    POTK["→ Kinematics3RRS"]
  end

  subgraph T5["GuiManualDispatcher thread"]
    GUIQ["GuiManualDispatcher queue"]
    GUIK["→ Kinematics3RRS"]
  end

  subgraph T3["Actuator thread"]
    ACT["ActuatorManager"]
    SERVO["ServoDriver"]
  end

  CAM --> CAMCB --> FQ
  FQ --> ST --> CTRL --> MIC --> KIN --> CQ
  ADS --> ADSCB --> ADSCB2 --> POTK
  UI --> UICB --> GUIQ --> GUIK
  MPU --> MPUCB --> MIC
  CQ --> ACT --> SERVO
```

---

## Component Responsibilities

### SystemManager

Coordinates runtime execution, manages threads, processes incoming events, and controls system state. Manual timing is fully delegated: potentiometer commands dispatch directly from the ADS1115 callback, and GUI commands dispatch from `GuiManualDispatcher`. The control thread handles only the automatic pipeline.

### BackendCoordinator

Owns the lifecycle of optional hardware backends: ADS1115 manual input and MPU-6050/ICM-20600 IMU. Starts, stops, and owns I2C/GPIO resources independently of pipeline orchestration.

### GuiManualDispatcher

Owns a dedicated worker thread and bounded freshest-data queue for GUI manual setpoints. When `setManualSetpoint()` is called, the dispatcher wakes immediately and dispatches the setpoint to `Kinematics3RRS` without depending on camera-frame timing.

### ICamera and Camera Backends

Provide frame acquisition. Multiple implementations can be used without affecting downstream processing.

### SunTracker

Processes image data and produces a target estimate including position and confidence.

### Controller

Transforms the target estimate into a platform-level motion command.

### ManualImuCoordinator

Handles manual input ownership and optional IMU-based adjustments. It builds manual setpoints and applies IMU correction where allowed by mode/source policy.

### Kinematics3RRS

Maps platform motion commands into actuator-specific commands based on mechanism geometry.

### ActuatorManager

Applies conditioning to actuator commands such as clamping and rate limiting to ensure safe output.

### ServoDriver and PCA9685

Convert actuator commands into hardware signals and communicate with the PWM controller.

### Input Devices

- `ADS1115ManualInput` provides potentiometer-based manual control input
- `Mpu6050Publisher` provides IMU data for orientation feedback

---

## Architectural Summary

The system is built as a pipeline of independent processing stages connected through well-defined interfaces. Each stage transforms data and passes it forward without direct knowledge of internal details of other components.

This structure enables:

- predictable data flow
- clear separation between computation and hardware access
- safe multi-threaded execution
- straightforward extension and modification of individual stages

The inter-thread queues are intentionally bounded:

- Frame queue capacity is small (2) to minimise latency and prevent stale frames accumulating.
- Command queue capacity is larger (8) to absorb short bursts without dropping actuator updates prematurely.

Both queues use a latest-wins policy, ensuring that the system prioritises current data while maintaining bounded memory and predictable behaviour.

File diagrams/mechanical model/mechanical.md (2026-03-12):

# 3RRS Mechanical Model | 3RRS 机械结构模型

[English](#english) | [中文](#中文)

---

## English

SolidWorks mechanical structure models for the Solar Stewart Tracker.

### File Formats

- `.SLDPRT` - SolidWorks part files
- `.SLDASM` - SolidWorks assembly files

### Main Components

#### Motion Platform System
- **The motion platform above.SLDPRT** - Upper motion platform
- **The static platform below.SLDPRT** - Lower static platform

#### Servo System
- **3230 Servo Motor.SLDPRT** - 3230 servo motor
- **Dual-axis servo.SLDASM** - Dual-axis servo assembly
- **Double-axis narrow U bracket.SLDPRT** - Dual-axis narrow U bracket
- **Double-axis wide U bracket.SLDPRT** - Dual-axis wide U bracket

#### Linkage Mechanism
- **L1 arm.SLDPRT** - L1 linkage arm
- **L2 arm.SLDPRT** - L2 linkage arm
- **ball head.SLDPRT** - Ball joint head
- **ball head neck.SLDPRT** - Ball joint neck

#### Steering Components
- **Real-axis steering wheel.SLDPRT** - Real-axis steering wheel
- **Imaginary axis steering wheel.SLDPRT** - Imaginary-axis steering wheel

#### Other Components
- **Raspberry Pi box sketch version.SLDPRT** - Raspberry Pi enclosure (sketch version)
- **sc-16-yp.SLDPRT** - SC-16-YP component
- **I M6.SLDPRT** - M6 fastener
- **di.SLDASM** - Main assembly

---

## 中文

太阳能 Stewart 追踪器的 SolidWorks 机械结构模型。

### 文件格式

- `.SLDPRT` - SolidWorks 零件文件
- `.SLDASM` - SolidWorks 装配体文件

### 主要组件

#### 运动平台系统
- **The motion platform above.SLDPRT** - 上层运动平台
- **The static platform below.SLDPRT** - 下层静态平台

#### 伺服系统
- **3230 Servo Motor.SLDPRT** - 3230 伺服电机
- **Dual-axis servo.SLDASM** - 双轴伺服装配体
- **Double-axis narrow U bracket.SLDPRT** - 双轴窄 U 型支架
- **Double-axis wide U bracket.SLDPRT** - 双轴宽 U 型支架

#### 连杆机构
- **L1 arm.SLDPRT** - L1 连杆臂
- **L2 arm.SLDPRT** - L2 连杆臂
- **ball head.SLDPRT** - 球头
- **ball head neck.SLDPRT** - 球头颈部

#### 转向组件
- **Real-axis steering wheel.SLDPRT** - 实轴转向轮
- **Imaginary axis steering wheel.SLDPRT** - 虚轴转向轮

#### 其他组件
- **Raspberry Pi box sketch version.SLDPRT** - 树莓派外壳草图版本
- **sc-16-yp.SLDPRT** - SC-16-YP 组件
- **I M6.SLDPRT** - M6 螺栓
- **di.SLDASM** - 主装配体

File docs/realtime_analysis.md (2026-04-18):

# Realtime Analysis

## Purpose

This document describes the realtime execution model and timing behaviour of the system.

---

## 1. Runtime Model

The system operates as a Linux userspace, event-driven runtime built on:

- poll() on file descriptors for application-level events  
- blocking std::condition_variable waits for inter-thread communication  
- GPIO edge-triggered callbacks for hardware sensor events  
- explicit state machine transitions  

No component introduces polling loops, sleep()-based pacing, or busy-waiting in the processing path.

---

## 2. Application Event Loop — LinuxEventLoop

src/app/LinuxEventLoop.cpp implements the headless runtime lifecycle. It multiplexes event sources using a single poll() call with an infinite timeout (-1).

File descriptors:

- signalfd → SIGINT / SIGQUIT / SIGHUP / SIGTERM → clean shutdown  
- timerfd (CLOCK_MONOTONIC) → configurable tick (default 30 Hz) → CLI servicing  
- stdin (dup'd) → terminal input  

The loop remains blocked in the kernel until an event occurs.

---

## 3. Inter-Thread Queues — ThreadSafeQueue

src/common/ThreadSafeQueue.hpp provides blocking data transfer between worker threads using std::mutex and std::condition_variable with wait_pop().

Two queues are defined in SystemManager:

- frame_q_ → ThreadSafeQueue<FrameEvent> → capacity 2 → push_latest()  
- cmd_q_ → ThreadSafeQueue<ActuatorCommand> → capacity 8 → push_latest()  

The push_latest() policy ensures consumers process the most recent data when under load. Queue sizes remain bounded.

---

## 4. Worker Threads

SystemManager owns two worker threads. A third dedicated thread is owned by GuiManualDispatcher.

Control thread (controlLoop_):

- blocks on frame_q_.wait_pop()  
- processes frames through SunTracker and Controller in automatic modes (SEARCHING / TRACKING)  
- drains frames without processing in MANUAL and FAULT states  
- is not involved in manual command generation  

GuiManualDispatcher thread:

- blocks on a bounded freshest-data queue (capacity 1)  
- wakes immediately when setManualSetpoint() is called  
- dispatches directly to Kinematics3RRS, independent of camera-frame timing  

Pot-manual path (no dedicated thread):

- ADS1115 ALERT/RDY GPIO edge fires onManualPotSample_() in the ADS1115 callback thread  
- dispatches directly to Kinematics3RRS from that callback context  

Actuator thread (actuatorLoop_):

- blocks on cmd_q_.wait_pop()  
- applies ActuatorManager → ServoDriver  
- no alternative actuation path exists  

---

## 5. Sensor Wakeups

Camera:

- SimulatedPublisher uses timerfd + poll() + eventfd  
- LibcameraPublisher delivers frames via callback-based backend  

Manual input:

- ADS1115ManualInput uses ALERT/RDY GPIO edge  
- callback dispatches directly to Kinematics3RRS in pot-manual mode  

IMU:

- Mpu6050Publisher uses GPIO data-ready interrupt  
- samples forwarded to coordinator  

---

## 6. Data Flow

Automatic path:

Frame callback  
→ frame_q_.push_latest(...)  
→ control thread wait_pop()  
→ SunTracker  
→ Controller  
→ ManualImuCoordinator::applyImuCorrection(...)  
→ Kinematics3RRS  
→ cmd_q_.push_latest(...)  
→ actuator thread wait_pop()  
→ ActuatorManager  
→ ServoDriver  

Pot-manual path:

ADS1115 ALERT/RDY GPIO edge  
→ onManualPotSample_() in ADS1115 callback thread  
→ ManualImuCoordinator builds manual setpoint  
→ applyImuCorrection  
→ Kinematics3RRS  
→ cmd_q_.push_latest(...)  
→ actuator thread wait_pop()  
→ ActuatorManager  
→ ServoDriver  

GUI-manual path:

setManualSetpoint() called (any thread)  
→ GuiManualDispatcher queue push_latest  
→ GuiManualDispatcher worker thread wakes immediately  
→ ManualImuCoordinator builds manual setpoint  
→ applyImuCorrection  
→ Kinematics3RRS  
→ cmd_q_.push_latest(...)  
→ actuator thread wait_pop()  
→ ActuatorManager  
→ ServoDriver  

All three paths share the downstream Kinematics → ActuatorManager → ServoDriver stages. The control thread handles only the automatic path. Both manual paths are independently event-driven.

---

## 7. Qt GUI Timing

Qt timers are used only for UI refresh and visualisation.

GUI slider interactions call setManualSetpoint(), which pushes to the GuiManualDispatcher queue. The dispatcher's dedicated worker thread wakes immediately and dispatches directly to Kinematics3RRS. Qt timers are never used as a control timing source.

---

## 8. IMU Policy in Manual Mode

Manual GUI input does not apply continuous IMU correction by default. Manual commands are generated directly from operator input.

IMU-assisted behaviour can be enabled through configured feedback modes.

---

## 9. Shutdown Behaviour

stop() performs:

- camera shutdown  
- backend shutdown  
- GuiManualDispatcher shutdown  
- queue termination  
- worker thread join  
- actuator neutral/park handling  
- servo driver shutdown  

Queues notify blocked threads during shutdown, ensuring clean exit.

---

## 10. Summary

The runtime follows a consistent event-driven execution model:

- all worker threads block on blocking primitives (poll, condition_variable)
- all wakeups originate from external events (file descriptors, queue notifications, GPIO interrupts)  
- no component introduces independent timing loops or polling  

The automatic path is processed by a single control thread. Both manual paths are independently event-driven: the pot path dispatches from the ADS1115 callback thread, and the GUI path dispatches from the GuiManualDispatcher worker thread. All three paths converge at Kinematics3RRS before actuation.

This structure ensures:

- separation between automatic, pot-manual, and GUI-manual timing  
- no camera-frame dependency in either manual path  
- separation between realtime processing and UI interaction  
- explicit ownership of timing and data flow

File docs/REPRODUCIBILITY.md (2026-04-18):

# Reproducibility

## Purpose

This document explains how to reproduce the  repository  from source using the files: `CMakeLists.txt`, `.github/workflows/`, `scripts/`, `.gitmodules`, `external/`, `src/`, and `docs/`.

---

## 0. Reference Platform

All latency measurements and hardware-smoke tests were captured on the following exact platform:

| Parameter | Value |
|---|---|
| Hardware | Raspberry Pi 5 Model B, 4 GB RAM |
| CPU | Broadcom BCM2712, Cortex-A76, 4-core, 2.4 GHz |
| Operating system | Raspberry Pi OS (Debian Trixie), 64-bit (aarch64) |
| Kernel | Linux 6.6.51+rpt-rpi-2712 (aarch64) |
| Compiler | GCC 12.2.0 (aarch64-linux-gnu) |
| libgpiod | 2.2.2 (built from source) |
| OpenCV | 4.10.0 (`libopencv-dev` via apt) |
| libcamera | 0.3.2 (`libcamera-dev` via apt) |
| Qt | Qt 5.15.8 (`qtbase5-dev libqt5charts5-dev` via apt) |

---

## 1. Source of Truth

The reproducible source of truth in this repository is:

| Path | Role |
|---|---|
| `src/` | Application and library source code |
| `CMakeLists.txt` | Top-level build definition |
| `.gitmodules` | External submodule declarations |
| `external/` | External support code checked out via submodules |
| `scripts/` | Build, test, documentation, latency, and packaging helper scripts |
| `.github/workflows/` | CI, documentation, hardware-smoke, and release automation |
| `artefacts/latency.csv` | Captured software latency measurements |
| `Doxyfile` | API documentation configuration |

---

## 2. External Dependencies

### Git Submodules

Two external repositories are declared in `.gitmodules`:

| Submodule | Path | URL |
|---|---|---|
| `libgpiod_event_demo` | `external/libgpiod_event_demo` | `https://github.com/berndporr/libgpiod_event_demo` |
| `libcamera2opencv` | `external/libcamera2opencv` | `https://github.com/berndporr/libcamera2opencv` |

These should be fetched with:

```bash
git submodule update --init --recursive
```

### System Packages

The Ubuntu CI workflow installs these packages directly:

```bash
sudo apt-get update
sudo apt-get install -y \
  autoconf \
  autoconf-archive \
  automake \
  cmake \
  g++ \
  libjsoncpp-dev \
  libtool \
  make \
  ninja-build \
  pkg-config \
  wget \
  xz-utils
```

The CI workflow then builds and installs **libgpiod v2.2.2** from source so that the C++ bindings are available.

For local Linux reproduction, the following additional packages may be needed depending on which optional features are enabled:

- `libopencv-dev` for OpenCV-dependent paths
- `libcamera-dev` for the Raspberry Pi libcamera backend
- `qtbase5-dev` for the Qt GUI target
- `graphviz` and `doxygen` for API documentation generation
- `i2c-tools` for Raspberry Pi hardware-smoke workflows

---

## 3. CMake Build Options

The top-level build defines the following options:

| Option | Default | Effect |
|---|---|---|
| `SOLAR_ENABLE_TESTS` | `ON` | Build and register test targets |
| `SOLAR_ENABLE_HW_TESTS` | `OFF` | Register real hardware smoke tests |
| `SOLAR_ENABLE_QT` | `ON` | Build the Qt GUI target if Qt5 is available |
| `SOLAR_TRY_LIBCAMERA` | `ON` | Probe for the libcamera backend |
| `SOLAR_TRY_OPENCV` | `ON` | Probe for OpenCV support |
| `SOLAR_ENABLE_COVERAGE` | `OFF` | Enable coverage compile/link flags where supported |

Feature probing behaves as follows:

- if OpenCV is not found, OpenCV-dependent functionality is disabled
- if libcamera is found but OpenCV is not found, the libcamera backend is disabled
- if Qt5 is not found, the Qt GUI target is skipped
- if `external/libgpiod_event_demo` is missing, GPIO demo support is disabled

---

## 4. Clean Reproduction Procedure

```bash
# Step 1 — clone
git clone <repo-url>
cd Solar-Stewart-Tracker

# Step 2 — initialise submodules
git submodule update --init --recursive

# Step 3 — install build dependencies
sudo apt-get update
sudo apt-get install -y \
  cmake \
  ninja-build \
  g++ \
  pkg-config \
  libjsoncpp-dev

# Optional packages for optional features
# sudo apt-get install -y libopencv-dev libcamera-dev qtbase5-dev doxygen graphviz i2c-tools

# Step 4 — configure
cmake -S . -B build -G Ninja -DCMAKE_BUILD_TYPE=Release

# Step 5 — build
cmake --build build --parallel

# Step 6 — run software tests
ctest --test-dir build --output-on-failure --verbose

# Step 7 — run the headless application
./build/solar_tracker

# Step 8 — run the Qt GUI if Qt was found at configure time
./build/solar_tracker_qt
```

---

## 5. Helper Scripts in `scripts/`

The repository  contains these helper scripts:

| Script | Purpose |
|---|---|
| `scripts/build_core.sh` | Configure and build the main software targets |
| `scripts/build_docs.sh` | Generate Doxygen documentation |
| `scripts/build_pi_debug.sh` | Configure a Pi-oriented debug build |
| `scripts/test_core.sh` | Run the software test suite |
| `scripts/test_pi_hw.sh` | Run hardware-labelled smoke tests on Raspberry Pi |
| `scripts/run_latency.sh` | Run the application with latency CSV export enabled |
| `scripts/package_release.sh` | Package a release zip |

---

## 6. CI Automation

Four workflows are defined in `.github/workflows/`:

| Workflow | Trigger | Runner |
|---|---|---|
| `ci.yml` | push to `main`, pull request to `main`, manual dispatch | `ubuntu-latest` |
| `doxygen.yml` | push to `main` or `master`, manual dispatch | `ubuntu-latest` |
| `release.yml` | release created, manual dispatch | `ubuntu-latest` |
| `pi-hardware-tests.yml` | manual dispatch | self-hosted `linux/arm64` |

### Standard CI (`ci.yml`)

The standard CI workflow performs the following steps:

1. checks out the repository with submodules
2. installs build dependencies
3. builds and installs `libgpiod` v2 with C++ bindings from source
4. configures the project with CMake and Ninja
5. builds the repository
6. runs `ctest --test-dir build --output-on-failure --verbose`

### Doxygen workflow (`doxygen.yml`)

The documentation workflow:

1. checks out the repository with submodules
2. installs `doxygen` and `graphviz`
3. runs `bash ./scripts/build_docs.sh`
4. uploads `docs/html` as the Pages artifact
5. deploys to GitHub Pages

### Release workflow (`release.yml`)

The release workflow:

1. checks out the repository with submodules
2. installs build dependencies
3. runs `bash ./scripts/build_core.sh build`
4. runs `bash ./scripts/package_release.sh build solar-stewart-tracker-release.zip`
5. uploads the packaged release artifact

### Raspberry Pi hardware-smoke workflow (`pi-hardware-tests.yml`)

The Pi workflow:

1. checks out the repository with submodules
2. installs Pi-side dependencies including `i2c-tools`
3. configures a debug build with `SOLAR_ENABLE_HW_TESTS=ON`
4. builds curated hardware-smoke targets
5. runs `bash ./scripts/test_pi_hw.sh "${BUILD_DIR}"`
6. uploads CTest logs and cache files as artifacts

---

## 7. Hardware Reproduction

The repository assumes a Raspberry Pi Linux target with the following hardware path available for full reproduction:

- Raspberry Pi running Linux
- I2C bus exposed as `/dev/i2c-1`
- PCA9685 PWM controller
- ADS1115 ADC for manual input sampling
- MPU6050 IMU
- GPIO event support through `libgpiod`
- Raspberry Pi camera path compatible with libcamera if the libcamera backend is used

### Hardware Test Environment Variables

The hardware-smoke script uses these environment variables:

| Variable | Default | Meaning |
|---|---|---|
| `SOLAR_RUN_CAMERA_HW_TESTS` | `1` | Enable camera hardware checks |
| `SOLAR_RUN_I2C_HW_TESTS` | `1` | Enable I2C hardware checks |
| `SOLAR_I2C_DEV` | `/dev/i2c-1` | I2C device path |

### Enabling Hardware Tests

```bash
cmake -S . -B build \
  -G Ninja \
  -DCMAKE_BUILD_TYPE=Debug \
  -DSOLAR_ENABLE_TESTS=ON \
  -DSOLAR_ENABLE_HW_TESTS=ON \
  -DSOLAR_ENABLE_QT=OFF \
  -DSOLAR_TRY_LIBCAMERA=OFF \
  -DSOLAR_TRY_OPENCV=OFF

cmake --build build --parallel
./scripts/test_pi_hw.sh build
```

---

## 8. Latency Data Reproduction

The repository includes `artefacts/latency.csv` as captured software latency evidence.

The same output path can be regenerated with:

```bash
./scripts/run_latency.sh build artefacts/latency.csv solar_tracker
```

This script sets the `SOLAR_LATENCY_CSV` environment variable before launching the application. At shutdown, the runtime `LatencyMonitor` writes per-frame measurements to the specified CSV path.

---

## 9. Non-Hardware Reproduction

If physical hardware is unavailable:

- the software test suite still runs
- hardware-smoke tests remain disabled by default because `SOLAR_ENABLE_HW_TESTS` defaults to `OFF`
- the application can run through the simulated camera backend path when hardware backends are not available

This allows code-level reproduction of the processing pipeline without requiring the full physical platform.

---

## 10. API Documentation Reproduction

A `Doxyfile` is  at the repository root.

Local generation:

```bash
doxygen Doxyfile
```

The repository also contains `scripts/build_docs.sh`, which is used by the GitHub documentation workflow.

---

## 11. Summary

This repository can be reproduced from source because it contains:

- the top-level build definition
- the declared submodules
- the build, test, latency, documentation, and packaging scripts
- the CI workflows
- the source tree
- the API documentation configuration
- the captured software latency artifact

A software-only reproduction path is available on a normal Linux system, and a fuller Raspberry Pi hardware-smoke path is defined separately for the target platform.

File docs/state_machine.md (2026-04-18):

# System State Machine

This document defines the runtime behaviour of the system as a state machine. It describes the implemented execution flow, including all states, transitions, and operational behaviour.

---

## 1. States

| State | Meaning | Outputs |
|---|---|---|
| IDLE | System not running | No motion |
| STARTUP | Initialisation in progress | Startup sequence in progress |
| NEUTRAL | Transitional safe positioning state | Configured startup park applied |
| SEARCHING | Target not confidently detected | Continuous automatic processing with safe behaviour |
| TRACKING | Target detected with sufficient confidence | Normal closed-loop automatic updates |
| MANUAL | User controls setpoint | Manual target dispatched via dedicated pot or GUI path |
| STOPPING | Shutdown in progress | Controlled stop sequence |
| FAULT | Failure state | Outputs stopped or held safe |

---

## 2. Transition Rules

| From | To | Trigger |
|---|---|---|
| IDLE | STARTUP | `start()` called |
| STARTUP | FAULT | camera null, driver start failure, manual backend failure, or camera start failure |
| STARTUP | NEUTRAL | successful initialisation |
| NEUTRAL | SEARCHING | startup park applied and `startup_mode == Auto` |
| NEUTRAL | MANUAL | startup park applied and `startup_mode == Manual` |
| SEARCHING | TRACKING | confidence ≥ threshold |
| TRACKING | SEARCHING | confidence < threshold |
| SEARCHING | MANUAL | `enterManual()` |
| TRACKING | MANUAL | `enterManual()` |
| NEUTRAL | MANUAL | `enterManual()` |
| MANUAL | SEARCHING | `exitManual()` |
| SEARCHING | STOPPING | `stop()` called |
| TRACKING | STOPPING | `stop()` called |
| MANUAL | STOPPING | `stop()` called |
| NEUTRAL | STOPPING | `stop()` called |
| STARTUP | STOPPING | `stop()` during startup |
| FAULT | STOPPING | `stop()` called |
| STOPPING | IDLE | shutdown complete |
| ANY ACTIVE STATE | FAULT | critical runtime failure |

---

## 3. State Descriptions

### IDLE

The system is inactive.

- camera is not running
- worker threads are not active
- no actuator commands are produced

### STARTUP

Initialisation phase.

- system marked as running
- camera null check performed
- actuator driver started
- queues reset
- worker threads started
- backend coordinator started
- camera streaming started
- failures lead to FAULT

### NEUTRAL

Short transitional state.

- startup park is applied using predefined actuator values
- transitions to SEARCHING (default) or MANUAL (if `startup_mode == Manual`)

### SEARCHING

System is active but target confidence is low.

- frames are processed continuously
- full automatic pipeline remains active
- motion remains bounded
- transitions to TRACKING when confidence increases

### TRACKING

System operates in closed-loop tracking mode.

- each frame triggers full automatic processing path
- controller, correction, kinematics, and actuator stages are active
- continuous actuator updates
- transitions back to SEARCHING if confidence drops

### MANUAL

User-controlled mode.

- activated via `enterManual()` or by `startup_mode == Manual`
- automatic controller updates are disabled
- the control thread handles only the automatic pipeline — it is **not involved** in manual mode dispatch

**Pot-driven manual (`ManualCommandSource::Pot`):**
- ADS1115 ALERT/RDY GPIO edge fires → `onManualPotSample_()` callback in the ADS1115 thread
- setpoint built via `ManualImuCoordinator` and dispatched **directly** to `Kinematics3RRS`
- timing is driven by the ADS1115 conversion rate — independent of camera frames

**GUI-driven manual (`ManualCommandSource::Gui`):**
- `setManualSetpoint()` → `GuiManualDispatcher::setSetpoint()` → push to bounded queue
- `GuiManualDispatcher` worker thread wakes **immediately** and dispatches directly to `Kinematics3RRS`
- timing is driven by operator input rate — independent of camera frames

Both paths use the same downstream `Kinematics3RRS → ActuatorManager → ServoDriver` pipeline.

IMU correction is applied via `ManualImuCoordinator::applyImuCorrection()` in both paths.

### STOPPING

Shutdown sequence.

- system marked as not running
- camera stopped
- backend coordinator stopped
- frame and command queues stopped
- processing threads joined
- neutral command applied
- driver stopped
- transitions to IDLE

### FAULT

Failure state.

- triggered by null camera, driver failure, backend failure, camera start failure, or invalid kinematics result
- actuator commands are halted or suppressed
- system requires explicit stop to recover

---

## 4. Runtime State Graph

```mermaid
stateDiagram-v2
    [*] --> IDLE

    IDLE --> STARTUP: start()

    STARTUP --> NEUTRAL
    STARTUP --> FAULT

    NEUTRAL --> SEARCHING: startup_mode == Auto
    NEUTRAL --> MANUAL: startup_mode == Manual

    SEARCHING --> TRACKING
    TRACKING --> SEARCHING

    SEARCHING --> MANUAL
    TRACKING --> MANUAL
    NEUTRAL --> MANUAL

    MANUAL --> SEARCHING

    SEARCHING --> FAULT
    TRACKING --> FAULT
    MANUAL --> FAULT
    NEUTRAL --> FAULT

    STARTUP --> STOPPING
    NEUTRAL --> STOPPING
    SEARCHING --> STOPPING
    TRACKING --> STOPPING
    MANUAL --> STOPPING
    FAULT --> STOPPING

    STOPPING --> IDLE
```

---

## 5. Startup and Shutdown Flow

```mermaid
flowchart TD
    A["start()"] --> B["set STARTUP"]
    B --> C{"camera null?"}
    C -- yes --> F1["set FAULT"]

    C -- no --> D{"driver start ok?"}
    D -- no --> F2["set FAULT"]

    D -- yes --> E["reset queues / reset manual state"]
    E --> G["start worker threads + GuiManualDispatcher"]

    G --> H{"backends start ok?"}
    H -- fail --> F3["stop and set FAULT"]

    H -- ok --> I{"camera start ok?"}
    I -- no --> F4["stop and set FAULT"]

    I -- yes --> J["set NEUTRAL"]
    J --> K["apply startup park"]

    K --> L{"startup_mode?"}
    L -- Manual --> M["set MANUAL"]
    L -- Auto --> N["set SEARCHING"]

    O["stop()"] --> P["set STOPPING"]
    P --> Q["camera stop"]
    Q --> R["backends stop"]
    R --> R2["stop GuiManualDispatcher"]
    R2 --> S["stop queues and join threads"]
    S --> T["apply neutral command"]
    T --> U["driver stop"]
    U --> W["set IDLE"]
```

---

## 6. Automatic vs Manual Processing

```mermaid
---
config:
  layout: dagre
---
flowchart TB
 subgraph COL1["Automatic path — control thread"]
    direction TB
        A1["Frame event"]
        A2["frame_q_.push_latest"]
        A3["control thread
wait_pop"]
        A4{"state?"}
        A5["SunTracker.onFrame"]
        A6["Controller.onEstimate"]
        A7["applyImuCorrection"]
        AO(["setpoint"])
        AX["drain — no processing"]
  end
 subgraph COL2["Pot manual path — ADS1115 callback thread"]
    direction TB
        B1["ADS1115 ALERT/RDY
GPIO edge"]
        B2["onManualPotSample_"]
        B3{"state==MANUAL
source==Pot?"}
        B4["buildManualSetpointFromPot"]
        B5["applyImuCorrection"]
        BO(["setpoint"])
        BX["discard"]
  end
 subgraph COL3["GUI manual path — GuiManualDispatcher thread"]
    direction TB
        C1["setManualSetpoint called"]
        C2["GuiManualDispatcher
.setSetpoint"]
        C3["push_latest to
bounded queue"]
        C4["worker thread
wakes immediately"]
        C5{"state==MANUAL
source==Gui?"}
        C6["buildManualSetpointFromGui"]
        C7["applyImuCorrection"]
        CO(["setpoint"])
        CX["discard"]
  end
 subgraph ACT["Actuator path — actuator thread"]
    direction TB
        J["cmd_q_.push_latest"]
        K["actuator thread
wait_pop"]
        L["ActuatorManager.onCommand"]
        M["ServoDriver.apply"]
  end
    A1 --> A2
    A2 --> A3
    A3 --> A4
    A4 -- SEARCHING
TRACKING --> A5
    A5 --> A6
    A6 --> A7
    A7 --> AO
    A4 -- MANUAL
FAULT --> AX
    B1 --> B2
    B2 --> B3
    B3 -- yes --> B4
    B4 --> B5
    B5 --> BO
    B3 -- no --> BX
    C1 --> C2
    C2 --> C3
    C3 --> C4
    C4 --> C5
    C5 -- yes --> C6
    C6 --> C7
    C7 --> CO
    C5 -- no --> CX
    AO --> KIN["⚙️  Kinematics3RRS.onSetpoint"]
    BO --> KIN
    CO --> KIN
    J --> K
    K --> L
    L --> M
    KIN --> J

     KIN:::shared
    classDef path fill:#f0f4ff,stroke:#6677aa,stroke-width:1.5px
    classDef shared fill:#fff8e1,stroke:#e6a800,stroke-width:2px
    classDef actuator fill:#f0fff4,stroke:#44aa66,stroke-width:1.5px
    classDef decision fill:#fff,stroke:#333,stroke-width:1.5px
    classDef discard fill:#fff0f0,stroke:#cc6666,stroke-width:1px
```

---

## 7. Implementation Notes

- automatic processing runs only in SEARCHING and TRACKING
- the control thread handles only the automatic path — it is not involved in manual dispatch
- pot manual commands are event-driven from the ADS1115 ALERT/RDY GPIO edge
- GUI manual commands are event-driven from the `GuiManualDispatcher` worker thread
- both manual paths dispatch directly to `Kinematics3RRS` without camera-frame dependency
- GUI manual mode does not use Qt timers as a control timing source
- invalid kinematic results prevent actuation and trigger FAULT
- state transitions are explicit and centrally controlled in `SystemManager`
- `BackendCoordinator` starts and stops ADS1115 and IMU backends during STARTUP and STOPPING

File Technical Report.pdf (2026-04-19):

# SunLock Lab

# Solar Stewart Tracker

## Technical Report

Realtime Embedded Systems — ENG5220 — University of Glasgow

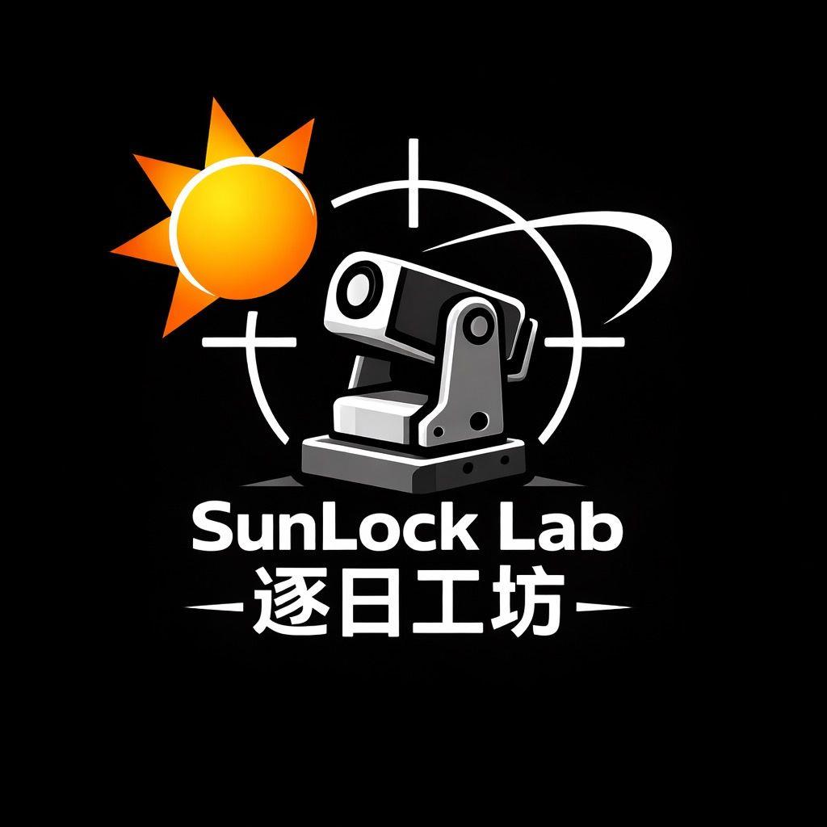
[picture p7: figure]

Student ID | Name | Primary Contribution
3127931H | Fadi Halteh | System architecture, state machine, IMU/ADS1115 integration, diagrams
3137140W | Jichao Wang | 3-RRS inverse kinematics, SystemFactory, AppConfig, entry structure
2429452Y | Ziming Yan | Vision subsystem (SunTracker), Qt GUI, live preview, charts
3139787A | Tareq A M Almzanin | Control layer, closed-loop logic, manual override, shared types
3099498Z | Zhenyu Zhu | PCA9685/ServoDriver, latency instrumentation, timing analysis

April 2026 · github.com/Real-Time-Stewart-Solar-Tracker/Solar-Stewart-Tracker

## 1. Introduction

The Solar Stewart Tracker is a realtime embedded system that continuously aims a solar-energy platform toward the sun. The mechanical platform is a 3-RRS Stewart-type parallel manipulator: a moving upper plate driven by three high-torque servos arranged at 120° intervals on a fixed base, connected through rod-end ball-joint linkages. A camera mounted above the platform captures live video. Software detects the sun position in each frame, calculates the error from centre, and drives the platform to correct it — all within a single C++17 Linux userspace process running on a Raspberry Pi 5.

The practical motivation is solar energy. A fixed panel only receives maximum irradiance at solar noon. Two-axis tracking increases daily energy yield by 25–40% at mid-latitudes. This project provides a low-cost embedded implementation using commodity hardware, open-source libraries, and a simple parallel linkage.

Beyond automatic tracking, the system supports two independently-driven manual modes: an operator can command the platform directly through potentiometers (read via an ADS1115 ADC with interrupt-driven acquisition) or through a Qt GUI. An MPU6050 IMU optionally provides platform-tilt feedback for improved accuracy.

The project is technically non-trivial because it combines four separate disciplines in one realtime pipeline: computer vision (brightness thresholding and weighted centroid estimation), proportional closed-loop control, 3-RRS Stewart-platform inverse kinematics (ZYX Euler rotation matrix, cosine-rule geometry per leg), and embedded hardware I/O (I2C, GPIO, PWM via PCA9685). All four must complete within one camera frame period — 33 ms at 30 fps.

### 1.1 Physical Behaviour

Input: IMX219 CSI camera at 30 fps. Output: PWM pulses on three servo channels via PCA9685 I2C driver board.

User interaction: headless CLI (manual/auto/set/threshold/quit/help commands) or Qt GUI with live camera preview, per-channel actuation charts, and manual position sliders. Potentiometer input uses interrupt-driven ADS1115 acquisition.

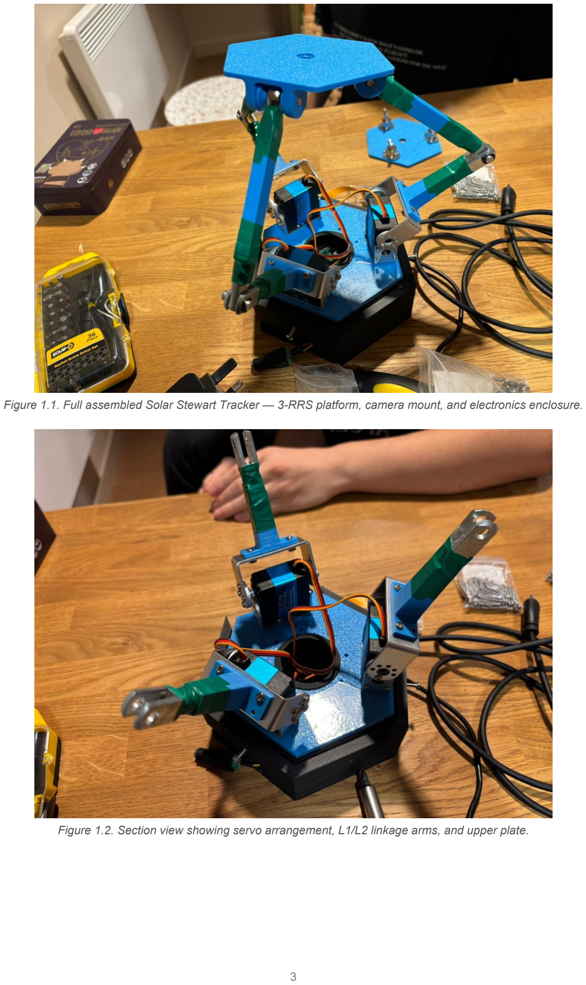
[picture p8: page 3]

Figure 1.1. Full assembled Solar Stewart Tracker — 3-RRS platform, camera mount, and electronics enclosure.

Figure 1.2. Section view showing servo arrangement, L1/L2 linkage arms, and upper plate.

## 2. System Overview

The entire system runs inside a single Linux userspace process. Hardware is accessed through standard kernel interfaces: I2C device files, the GPIO chip via libgpiod, and the CSI camera via libcamera. There is no kernel module and no RTOS.

### 2.1 Sensing

Camera: an IMX219 8 MP module connects via CSI ribbon to the Raspberry Pi 5. Frames are delivered at 640×480, RGB888, 30 fps through a libcamera → libcamera2opencv bridge. Each completed DMA transfer fires a callback in the camera backend thread.

IMU: an MPU6050 accelerometer/gyroscope sits on I2C bus 1 at address 0x68. Its data-ready interrupt fires on GPIO27. The system reads 3-axis acceleration on each interrupt and uses the result for optional platform-tilt correction.

Manual input: an ADS1115 16-bit ADC sits on I2C bus 1 at address 0x48. Its ALERT/RDY pin fires on GPIO17 when a conversion is complete. Two channels read the wiper voltages from tilt and pan potentiometers.

### 2.2 Computation

The automatic pipeline runs entirely in a dedicated control thread: SunTracker finds the bright pixel cluster and emits a weighted centroid with confidence; Controller converts image-plane error into tilt/pan setpoints in radians; ManualImuCoordinator applies optional IMU correction; Kinematics3RRS solves the inverse kinematics to produce three servo angles in degrees; ActuatorManager applies clamping and rate limiting.

Manual paths are fully independent. Both the potentiometer path and the GUI path have their own threads and dispatch directly to Kinematics3RRS, without passing through the control thread and without any dependence on camera frames.

### 2.3 Actuation

ServoDriver converts degree-valued commands to PWM pulse widths and writes them to the PCA9685 PWM controller over I2C. The PCA9685 generates the actual PWM signals, which removes timing load from the processor. Three RDS3230 high-torque servos drive the 3-RRS linkage arms.

### 2.4 Operational States

State | Entry Condition | Behaviour
IDLE | Initial or after shutdown | System inactive. No frames acquired, no actuator output.
STARTUP | start() called | Camera null-check, servo driver start, queue reset, thread launch, sensor backend start.
NEUTRAL | STARTUP succeeds | Startup park position applied to all three servos.
SEARCHING | startup_mode == Auto | Full automatic pipeline active. Target confidence below threshold.
TRACKING | confidence ≥ threshold | Closed-loop automatic tracking. Sun centroid locked.
MANUAL | enterManual() from any state | Pot or GUI manual path active. Automatic pipeline suspended.
FAULT | Any hardware or kinematics failure | Actuator output suppressed. Requires explicit stop() to recover.
STOPPING | stop() from any state | Camera and backends stopped, threads joined, servos parked, state set to IDLE.

Table 2.1. Runtime state machine. All transitions are explicit and logged.

## 3. Hardware Requirements

This section covers every hardware component required to build and run the system in hardware mode. Table 3.1 lists the full bill of materials.

Component | Model / Specification | Interface | Role
Raspberry Pi 5 (8 GB) | BCM2712, Cortex-A76 quad-core, 64-bit | GPIO / CSI / I2C | Central processor. Runs the Linux userspace process.
Camera Module | IMX219 8 MP CSI Module | CSI ribbon (FPC) | 30 fps frame source. Camera DMA completion wakes the control thread.
PCA9685 PWM Driver | 16-ch I2C PWM, addr 0x40 | I2C bus 1 | Generates servo PWM signals independently of the processor.
Servo × 3 | RDS3230, 20 kg·cm, 270° travel | PWM from PCA9685 | Drives the three 3-RRS linkage arms.
MPU6050 IMU | 3-axis accel/gyro, addr 0x68 | I2C + GPIO27 INT | Platform-tilt feedback. INT pin fires when a sample is ready.
ADS1115 ADC | 16-bit, 4-ch, addr 0x48 | I2C + GPIO17 ALERT | Reads two potentiometers. ALERT/RDY fires when a conversion finishes.
Potentiometers × 2 | 10 kΩ linear rotary | Analog → ADS1115 A0/A1 | Manual tilt and pan input.
External PSU | 5–6 V, high-current | PCA9685 V+ rail | Servo power supply. Keeps the Pi from browning out under load.
3-RRS Platform | Acrylic / PLA 3D-printed | Mechanical | Parallel linkage with M6 rods and SA6TK ball joints.
FPC ribbon cable | Pi 5 CSI compatible | Camera interface | Connects IMX219 to the Pi CSI port.
Breadboard + jumpers | Standard prototyping kit | GPIO / I2C | I2C bus wiring and GPIO interrupt routing.
Fasteners | M2–M6 threaded rod, rod-ends, hex nuts | Mechanical | Platform arm assembly and length adjustment for calibration.

Table 3.1. Full bill of materials. Both ADS1115 and MPU6050 were chosen specifically because they provide hardware data-ready interrupt pins (ALERT/RDY and INT), which allow the software to block on a GPIO edge rather than polling I2C. Total estimated cost: £217.

### 3.1 I2C Bus and GPIO Assignments

Physical Pin | Signal | Direction | Connection
Pin 1 | 3.3 V | Power | PCA9685 VCC · ADS1115 VDD · MPU6050 VCC
Pin 3 | GPIO2 SDA | Bidirectional | PCA9685 SDA · ADS1115 SDA · MPU6050 SDA
Pin 5 | GPIO3 SCL | Bidirectional | PCA9685 SCL · ADS1115 SCL · MPU6050 SCL
Pin 6 | GND | Power | All module grounds and external PSU ground (common ground)
Pin 11 | GPIO17 | Input | ADS1115 ALERT/RDY — conversion-complete interrupt via libgpiod

Physical Pin | Signal | Direction | Connection
Pin 13 | GPIO27 | Input | MPU6050 INT — data-ready interrupt via libgpiod
CSI | CSI lanes | Input | IMX219 camera module FPC ribbon

Table 3.2. Raspberry Pi 5 pin assignments. All three I2C devices share bus 1. GPIO17 and GPIO27 carry the hardware interrupt lines.

Critical wiring rules: all grounds must connect to a common plane; servo power must come from the external PSU through PCA9685 V+, never from Pi GPIO pins; PCA9685 has two separate power domains (VCC = 3.3 V logic; V+ = 5–6 V servo power); never swap SDA and SCL.

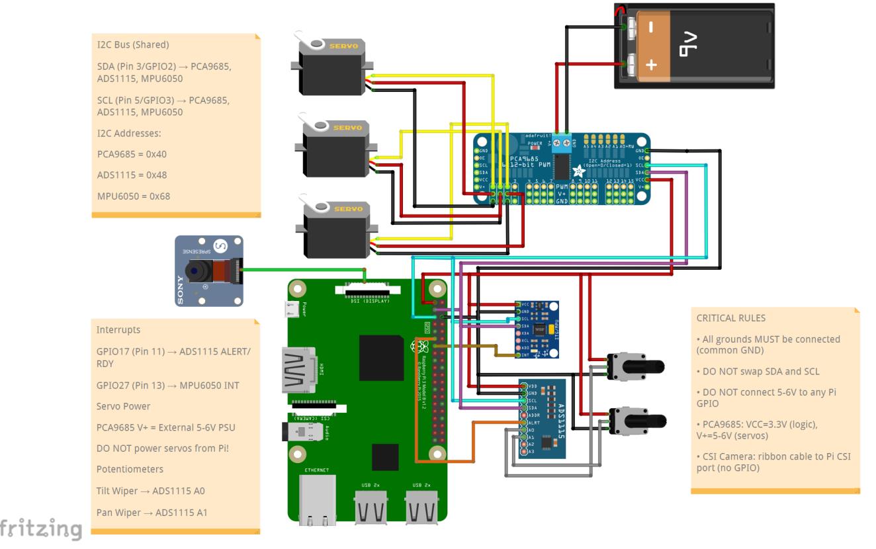
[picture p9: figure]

Figure 3.1. Circuit wiring diagram showing the shared I2C bus, GPIO17 and GPIO27 interrupt lines, servo power rail, and potentiometer inputs. Editable Fritzing source: diagrams/circuit_diagram.fzz.

## 4. Mechanical Platform

The actuator mechanism is a 3-RRS Stewart-type parallel platform. The "3-RRS" label describes the three identical kinematic chains connecting the base to the moving plate, each with one Revolute joint (the servo horn), one Revolute joint (a ball-end clevis bracket), and one Spherical joint (a rod-end ball joint).

Three RDS3230 servos are fixed to the base plate at 120° intervals. Each servo drives an upper arm (L1 = horn length). The arm connects through a threaded M6 rod (L2 = rod length) with SA6TK rod-end ball joints to the moving upper platform. This arrangement gives two controlled degrees of freedom — pitch and roll — while yaw is constrained by the three-chain symmetry.

The inverse kinematics problem is: given a desired platform tilt expressed as pan and tilt in radians, compute the three servo horn angles needed to achieve that pose. Kinematics3RRS solves this using a ZYX intrinsic Euler rotation matrix, a cosine-rule calculation per leg, and branch selection that prefers horn-up configurations and continuity with the previous angle. If a configuration is geometrically unreachable, the solver falls back to the last valid command.

All geometric parameters — base radius (Rb), platform radius (Rp), home height (h), horn length (L1), rod length (L2), per-leg anchor angles — are calibration values in AppConfig. The full SolidWorks CAD assembly is in the repository at diagrams/mechanical model/3rrs/.

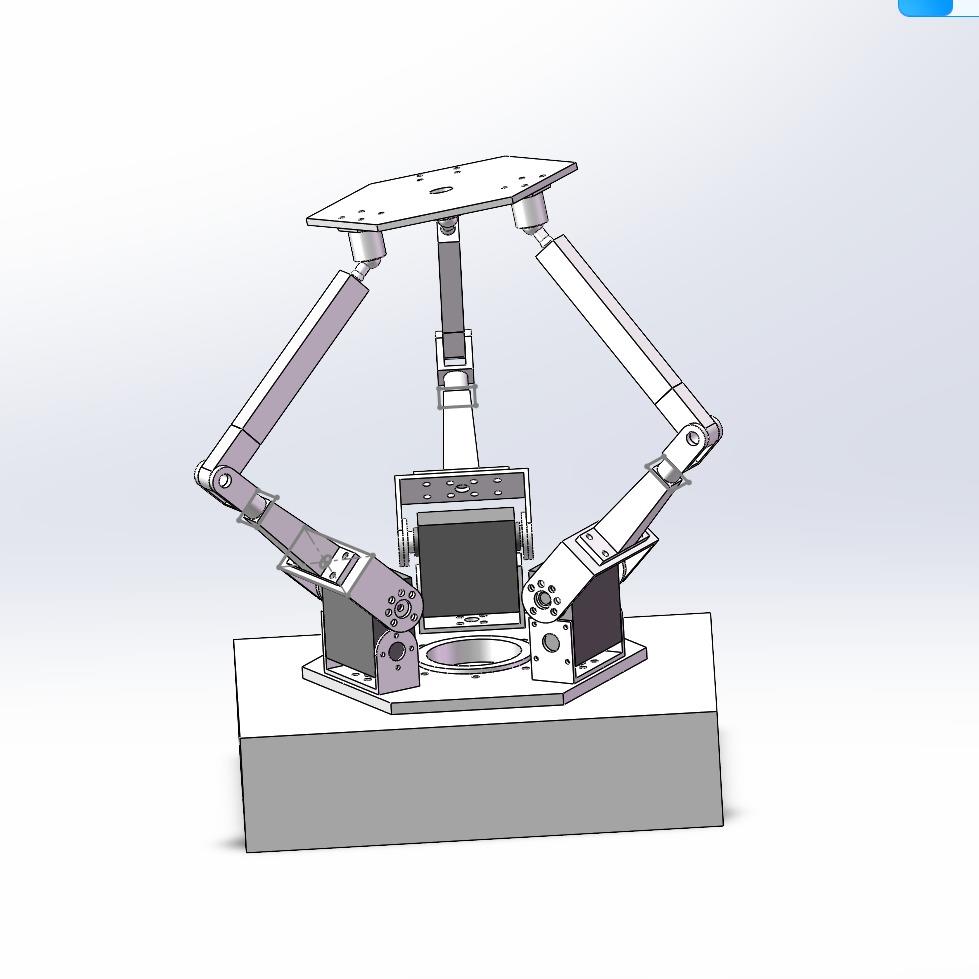
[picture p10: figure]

Figure 4.1. SolidWorks 3-RRS model showing base plate, three servo positions at 120°, L1 upper arms, M6 rod links with ball joints, and the moving upper platform.

## 5. Why Realtime?

The sun moves slowly roughly 2.7 pixels per second at 640×480 with a 60° horizontal field of view. The realtime requirement is not driven by the sun's angular speed. It is driven by something more fundamental: the control loop must respond to a physical event (a completed camera exposure) within a fixed deadline (the next frame period).

At 30 fps the deadline is 33 ms. Here is what happens if processing misses it:

- A frame arrives but the control thread is still processing the previous one. The new frame sits in the queue.
- When the control thread finishes, it picks up the queued frame — but that frame is already 33 ms old. The platform is now tracking a position from the past.
- Under sustained overload, queued frames accumulate. Each one adds 33 ms of lag. At large lags the proportional controller becomes unstable because it is reacting to positions the sun has already left.

The measured average end-to-end pipeline latency is 2.40 ms. The worst-case measured latency is 4.55 ms. Both are well below the 33 ms. There is no systematic backlog.

A polling approach — where a loop checks whether a new frame is available at regular intervals using sleep() — would not work reliably here. Between frames the thread wastes CPU cycles doing nothing useful. When a frame does arrive, the thread might not see it for up to one poll interval. And because sleep() timing is subject to OS scheduler decisions, the actual wakeup time is non-deterministic. The event-driven approach used here has none of these problems: the control thread blocks in the kernel and wakes the instant a frame is pushed into its queue.

The same argument applies to the sensors. I2C reads from the ADS1115 and MPU6050 only block for the duration of the transfer itself — they do not wait for new data. If the software polled those devices at a fixed rate, sample timing would depend on the software's scheduling, not the sensor's conversion rate. By using the hardware data-ready interrupt pins (ALERT/RDY and INT), the software sleeps until the sensor itself signals that new data is ready. Sample timing is therefore governed entirely by the hardware.

Stage | Description
Physical event | Sun moves; light pattern on IMX219 sensor shifts.
Sensing | Camera DMA transfer completes. FrameEvent callback fires in camera thread.
Queue handoff | Frame pushed to frame_q_ (capacity 2, push_latest). Control thread woken by condition_variable.
Vision | SunTracker thresholds frame, counts bright pixels, computes weighted centroid. Emits SunEstimate with confidence.
Control | Controller applies proportional gain, deadband, and saturation. Emits PlatformSetpoint in radians.
IMU correction | ManualImuCoordinator optionally applies tilt offset from latest IMU sample.
Inverse kinematics | Kinematics3RRS: ZYX Euler rotation matrix → cosine-rule per leg → three servo angles in degrees.
Command queue | ActuatorCommand pushed to cmd_q_ (capacity 8). Actuator thread woken by condition_variable.
Safety check | ActuatorManager applies per-channel clamping and slew-rate limiting.
Hardware output | ServoDriver converts degrees to PWM pulse width. Writes to PCA9685 over I2C. PWM pulses drive servos.
Physical response | Servo arms move. Linkage tilts platform. Solar surface faces the sun.

Table 5.1. The complete event-to-actuation chain from light source movement to servo response.

## 6. Software Architecture

The software is written in C++17 and built with CMake 3.16+ using Ninja. Everything runs inside a single Linux process structured as a forward-only staged pipeline. Each stage owns a specific transformation and communicates with the next stage through a registered callback function — it never queries the upstream stage for data.

### 6.1 The Automatic Pipeline

ICamera → SunTracker → Controller → ManualImuCoordinator → Kinematics3RRS → ActuatorManager → ServoDriver

Each stage receives typed input and produces typed output. The data types flowing through are:

- FrameEvent — raw pixel data, format, dimensions, stride, frame ID, capture timestamp
- SunEstimate — centroid (cx, cy) in pixels, confidence in [0,1], frame ID, timestamp
- PlatformSetpoint — tilt_rad, pan_rad, frame ID, timestamp
- ActuatorCommand — actuator_targets[3] in degrees, status code (Ok / KinematicsFallback / KinematicsInvalidConfig), frame ID

### 6.2 Class Responsibilities

Class | Responsibility
SystemManager | Thin runtime orchestrator. Owns two worker threads, two bounded queues, and the state machine. About 380 lines.
BackendCoordinator | Owns ADS1115 and MPU6050 backend lifecycle (I2C construction, GPIO setup, start/stop). Exposes only start() and stop() to SystemManager.
GuiManualDispatcher | Dedicated worker thread and capacity-1 bounded queue for GUI manual setpoints. Wakes immediately on operator input and dispatches directly to Kinematics3RRS, independent of camera timing.
ICamera | Pure virtual interface: registerFrameCallback(), start(), stop(), isRunning(). Four methods. Keeps the pipeline independent of which camera backend is in use.
LibcameraPublisher | Concrete ICamera. Delivers frames via libcamera DMA completion callback.
SimulatedPublisher | Concrete ICamera. Uses timerfd + poll() to pace frames at 30 Hz for software testing without hardware.
SunTracker | Vision stage. Thresholds for brightness, counts qualifying pixels, computes weighted centroid. Emits SunEstimate.
Controller | Control stage. Proportional gain with deadband re-scaling and saturation. Emits PlatformSetpoint.
ManualImuCoordinator | Coordinates manual input source ownership and optional IMU tilt correction. Builds manual setpoints for both pot and GUI paths.
Kinematics3RRS | 3-RRS inverse kinematics. ZYX Euler rotation matrix + cosine-rule per leg. Branch selection and fallback on unreachable configurations.
ActuatorManager | Safety layer. Per-channel output clamping and optional slew-rate limiting.
ServoDriver | Final output. Converts degrees to PWM pulse widths and writes via PCA9685. Parks servos on start and stop. Three startup policies.
PCA9685 | Low-level I2C PWM chip access through the II2CDevice interface.

Class | Responsibility
ThreadSafeQueue<T> | Blocking bounded queue. push_latest() drops the oldest item when full. wait_pop() blocks on a condition variable.
LatencyMonitor | Records std::chrono::steady_clock timestamps at four points per frame. Exports CSV and prints summary on shutdown.
LinuxEventLoop | Headless application event loop. Multiplexes signalfd, timerfd, and stdin on a single poll() call.
SystemFactory | Composition root. Selects concrete backends, wires the runtime graph, injects dependencies. The only place that knows about concrete types.

Table 6.1. Class responsibilities. Each class has one reason to change.

### 6.3 Callback Map

All stage-to-stage communication uses registered std::function callbacks for incoming events, and setter-style methods for outgoing commands. No stage polls an upstream stage.

Publisher | Subscriber | Data Type | Registration
ICamera | SystemManager | FrameEvent | camera_->registerFrameCallback()
SunTracker | SystemManager | SunEstimate | tracker_.registerEstimateCallback()
Controller | SystemManager | PlatformSetpoint | controller_.registerSetpointCallback()
Kinematics3RRS | SystemManager | ActuatorCommand | kinematics_.registerCommandCallback()
ActuatorManager | SystemManager | ActuatorCommand | actuatorMgr_.registerSafeCommandCallback()
IIMU | BackendCoordinator | ImuSample | registerEventCallback()
ADS1115ManualInput | BackendCoordinator | ManualPotSample | registerCallback()
LatencyMonitor | SystemManager | per-frame metrics | latency_.registerObserver()

Table 6.2. Callback registration map.

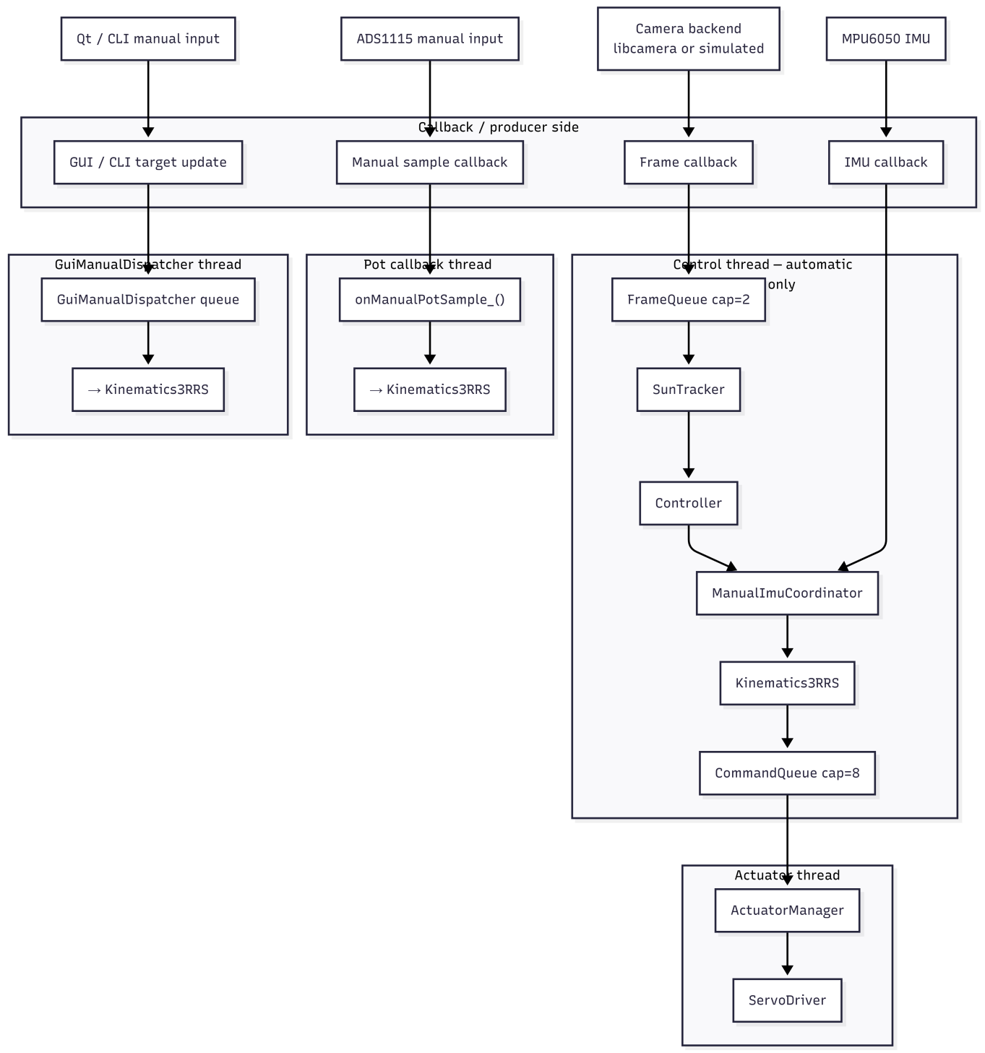
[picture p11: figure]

Figure 6.2. Threaded event-driven architecture diagram showing all threads, blocking primitives, queues, and data paths.

## 7. Realtime and Event-Driven Design

The core design rule throughout the system is that no thread ever checks or polls for work. Every thread blocks on a kernel-backed primitive and wakes only when an external event delivers something to process. This means zero CPU time is spent waiting, the response latency is as low as the kernel scheduler allows, and there is no timing error introduced by fixed-rate polling intervals.

### 7.1 Camera Path

LibcameraPublisher delivers frames through a libcamera DMA completion callback. When a camera frame is ready, the callback fires in the camera backend thread. The handler records a capture timestamp, pushes the FrameEvent into frame_q_ via push_latest(), and returns immediately — it does nothing slow. The control thread, which has been sleeping on frame_q_.wait_pop(), wakes up and processes the frame.

SimulatedPublisher uses the same downstream path but replaces the DMA callback with a timerfd + poll() loop at 30 Hz. This is the right approach when there is no real hardware event to block on — the timerfd provides a proper kernel-backed event source rather than a sleep() call.

// SimulatedPublisher worker thread:
timer_fd_ = timerfd_create(CLOCK_MONOTONIC, TFD_CLOEXEC); timerfd_settime(timer_fd_, 0, &spec, nullptr); // fires every 33 ms
while (running_) {
poll(fds, 2, -1); | // sleeps until timer fires
read(timer_fd_, &expirations, sizeof(expirations));
synthesiseAndDeliverFrame(); | // same path as hardware
}

### 7.2 Control Thread

The control thread runs controlLoop_(), which blocks on frame_q_.wait_pop(). When a frame is available, the thread checks the current system state. In SEARCHING or TRACKING it runs the full automatic pipeline: SunTracker → Controller → ManualImuCoordinator → Kinematics3RRS, then pushes the resulting ActuatorCommand into cmd_q_. In MANUAL or FAULT it drains frames without processing to keep the queue clear.

This separation between the fast camera callback (push to queue, return) and the slower vision and control work (done in the control thread) is deliberate. The camera callback must always complete quickly so the libcamera backend is never stalled. Vision processing takes ~2.4 ms on average and has variable runtime — it belongs in a separate blocking thread, not in the callback.

### 7.3 Actuator Thread

The actuator thread blocks on cmd_q_.wait_pop(). When a command arrives, it passes through ActuatorManager for clamping and slew limiting, then ServoDriver converts it to PWM pulse widths and writes to the PCA9685 over I2C. The thread returns to wait_pop() immediately after.

Separating the actuator thread from the control thread means I2C write timing (0.017 ms average) is decoupled from vision processing jitter (2.38 ms average). Without this separation, servo outputs would be delayed by the full vision processing time on every frame.

### 7.4 Data-Ready GPIO Pattern — ADS1115 and MPU6050

I2C only blocks for the duration of a register transfer — it does not wait for a sensor to produce new data. Polling I2C at a fixed rate wastes bus bandwidth and ties sample timing to software scheduling rather than the sensor's conversion rate. The correct approach is to use the sensor's data-ready output pin to signal when a result is available.

Both sensors in this project have such pins:

- ADS1115 ALERT/RDY (GPIO17): fires when a conversion is complete. The ADS1115ManualInput thread blocks on libgpiod wait_edge_events(). When the edge fires, the thread reads the ADC result over I2C and invokes the sample callback. Timing is governed by the ADS1115 conversion rate, not the software.
- MPU6050 INT (GPIO27): fires when a new inertial sample is ready. The Mpu6050Publisher thread blocks on the same libgpiod pattern. When the edge fires, six I2C registers are read and the sample forwarded to ManualImuCoordinator.

// Mpu6050Publisher — data-ready GPIO pattern: gpio_pin_.registerCallback([this](const gpiod::edge_event& event) { onGpioEvent_(event); // only called when INT pin fires
});
gpio_pin_.start(config_.gpio_pin_no, config_.gpio_chip_no);
// The gpio_pin_ thread internally runs:
// | while (running) {
// | request->wait_edge_events(...); | // sleeps until interrupt fires
// | read 6 I2C registers | // only then touches the bus
// | invoke callback with sample | // forward to coordinator
// | }

### 7.5 Potentiometer Manual Path

When ADS1115ManualInput fires its callback, the system is in the ADS1115 callback thread. Rather than queuing the sample for the control thread to pick up later, the pot-manual path dispatches directly: ManualImuCoordinator builds a platform setpoint, applies IMU correction if enabled, and calls Kinematics3RRS. This makes manual potentiometer response independent of camera frame timing entirely.

### 7.6 GUI Manual Path

When the operator moves a slider, the Qt GUI thread calls SystemManager::setManualSetpoint(), which calls GuiManualDispatcher::setSetpoint(). The dispatcher pushes the setpoint to its internal capacity-1 queue and returns. The GuiManualDispatcher worker thread, which has been blocking on that queue, wakes immediately and runs the same dispatch path as the pot: ManualImuCoordinator → Kinematics3RRS → cmd_q_.

Qt timers are used only for display refresh and chart updates. They never trigger actuator commands.

### 7.7 IMU Path

The MPU6050 callback thread forwards samples to ManualImuCoordinator::updateImuSample(). Samples do not directly trigger actuation. They update the correction offset that gets applied the next time any setpoint passes through applyImuCorrection(). The IMU and the control pipeline are decoupled.

### 7.8 Application Event Loop

The main thread runs LinuxEventLoop, which multiplexes three file descriptors on a single poll(-1) call. It sleeps until one of three events occurs: a Unix signal (SIGINT/SIGTERM via signalfd, which triggers clean shutdown), a 30 Hz timerfd tick (for CLI heartbeats), or stdin input (for commands). There is no code in main() — it constructs an Application and calls run().

// main.cpp — the entire file:

#include "app/Application.hpp" int main() {

solar::app::Application app; return app.run();
}

// LinuxEventLoop::run() — all event handling:
int sig_fd | = signalfd(-1, &mask, SFD_CLOEXEC); | // Unix signals
int timer_fd = timerfd_create(CLOCK_MONOTONIC, ...); // 30 Hz tick
// stdin duplicated as fds[2]
while (!done) {
poll(fds, 3, -1); | // sleeps until any event
if (fds[0].revents & POLLIN) handleSignal(); | // SIGINT → shutdown
if (fds[1].revents & POLLIN) cli_.onTick(); | // CLI heartbeat
if (fds[2].revents & POLLIN) cli_.onInput(); | // user command
}

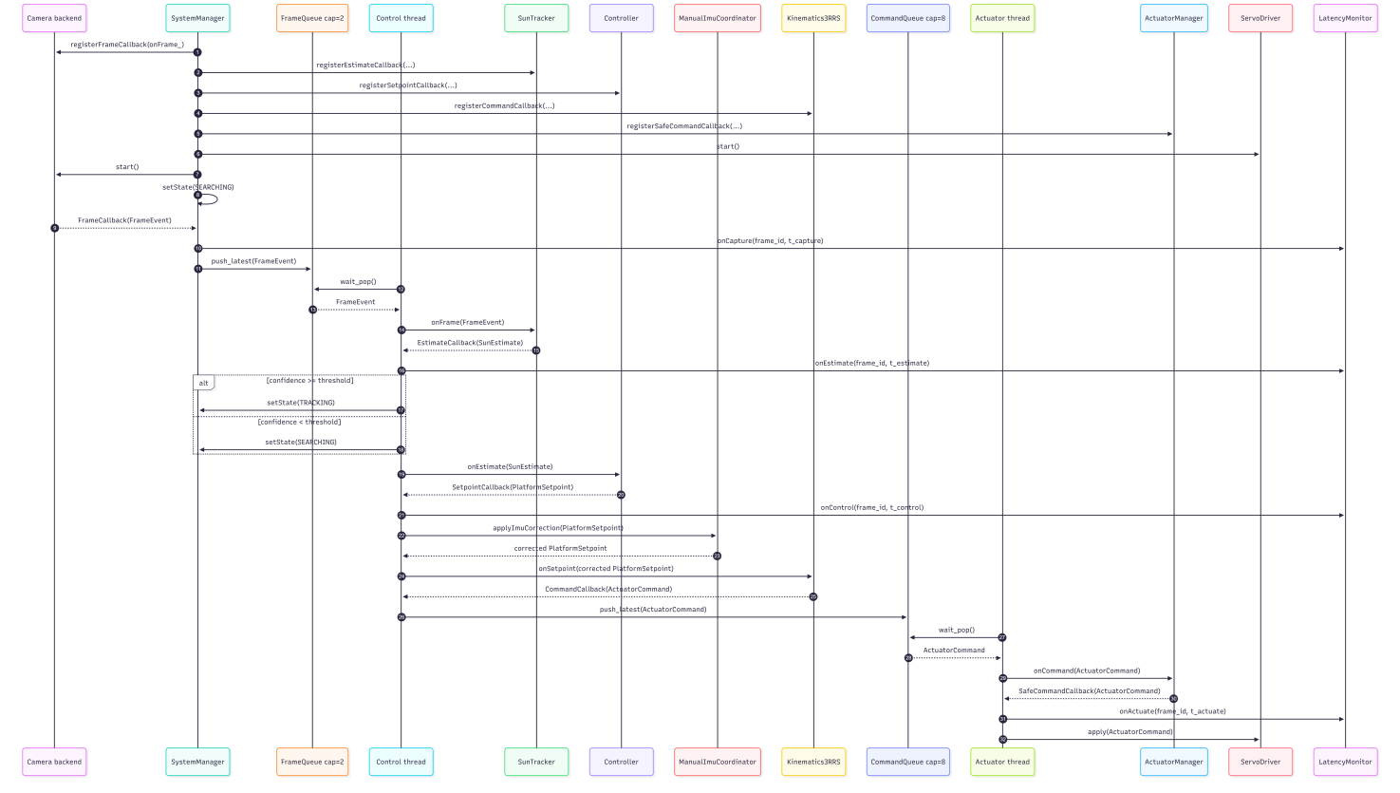
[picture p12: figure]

Figure 7.1. Sequence diagram — automatic pipeline from start() to steady-state tracking. Every inter-stage transition is callback-driven or queue-pushed.

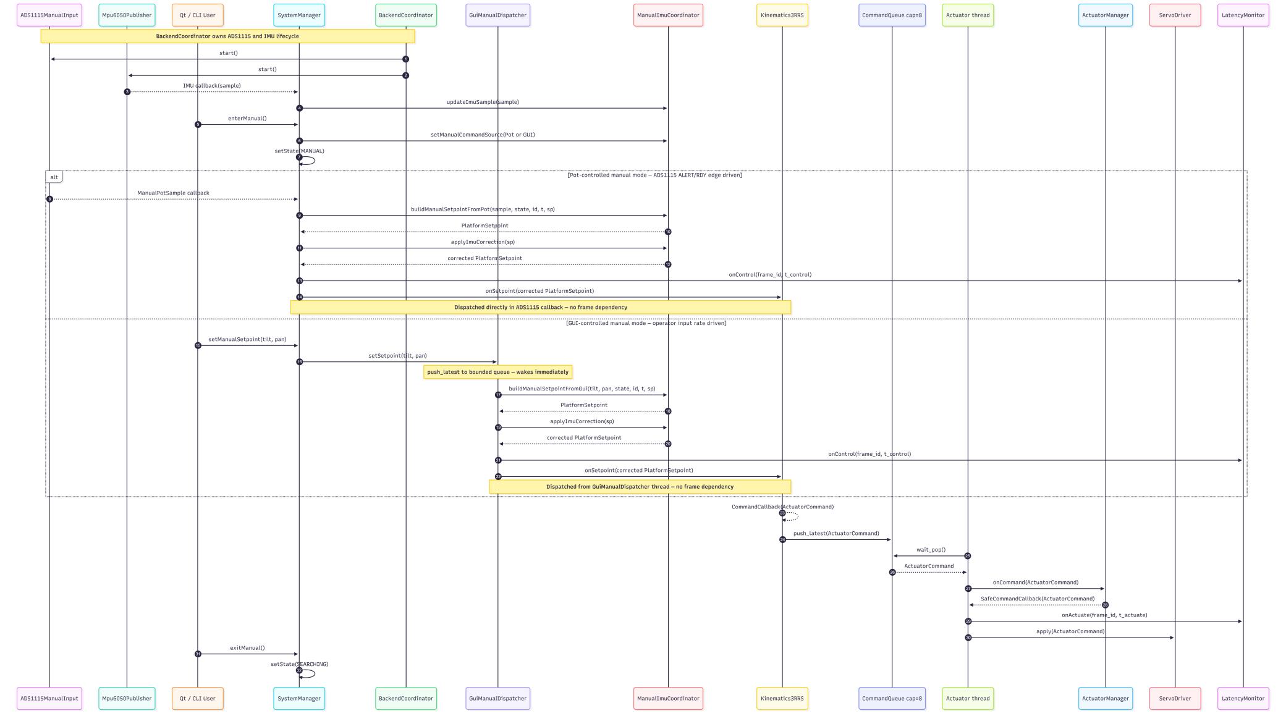
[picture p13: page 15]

Figure 7.2. Sequence diagram — manual input and IMU update paths. Both pot and GUI paths operate independently of camera frames.

## 8. Threading Model

The system uses eight threads. Each one blocks on a kernel-backed primitive and has a single, named role. The table below lists them all.

Thread | Blocking Primitive | Work Performed | Output
Camera (hardware) | libcamera DMA callback | Receive FrameEvent from libcamera | frame_q_.push_latest()
Camera (simulated) | timerfd + poll() | Synthesise frame at 30 Hz | frame_q_.push_latest()
Control | frame_q_.wait_pop( ) | SunTracker → Controller → ManualImuCoordinato r → Kinematics3RRS | cmd_q_.push_latest()
Actuator | cmd_q_.wait_pop() | ActuatorManager conditioning | ServoDriver.apply() → I2C
GuiManualDispatche r | queue condition_variable | Build manual setpoint via ManualImuCoordinato r | Kinematics3RRS → cmd_q_
ADS1115 | GPIO ALERT/RDY (libgpiod) | Read ADC result over I2C | ManualImuCoordinator → Kinematics3RRS → cmd_q_
MPU6050 | GPIO INT (libgpiod) | Read 6 IMU registers over I2C | ManualImuCoordinator.updateImuSample( )
Main / event loop | poll() on signalfd/timerfd/stdi n | Signal handling, CLI commands | SystemManager.start/stop/enterManual

Table 8.1. All eight threads with blocking primitive, work, and output. No thread uses sleep(), polling, or busy-waiting.

The frame queue (capacity 2) separates the camera callback thread from the control thread. The command queue (capacity 8) separates the control thread from the actuator thread. Both queues use the push_latest() policy: when a queue is full, the oldest item is dropped before the newest is inserted. This keeps both queues bounded in size and ensures the consumer always gets the most recent data.

All three processing paths — automatic, pot-manual, and GUI-manual — converge at Kinematics3RRS. Because all three can call Kinematics3RRS concurrently, the IK solver protects its internal state (q_prev_ and last_valid_deg_) with a mutex (ik_mtx_).

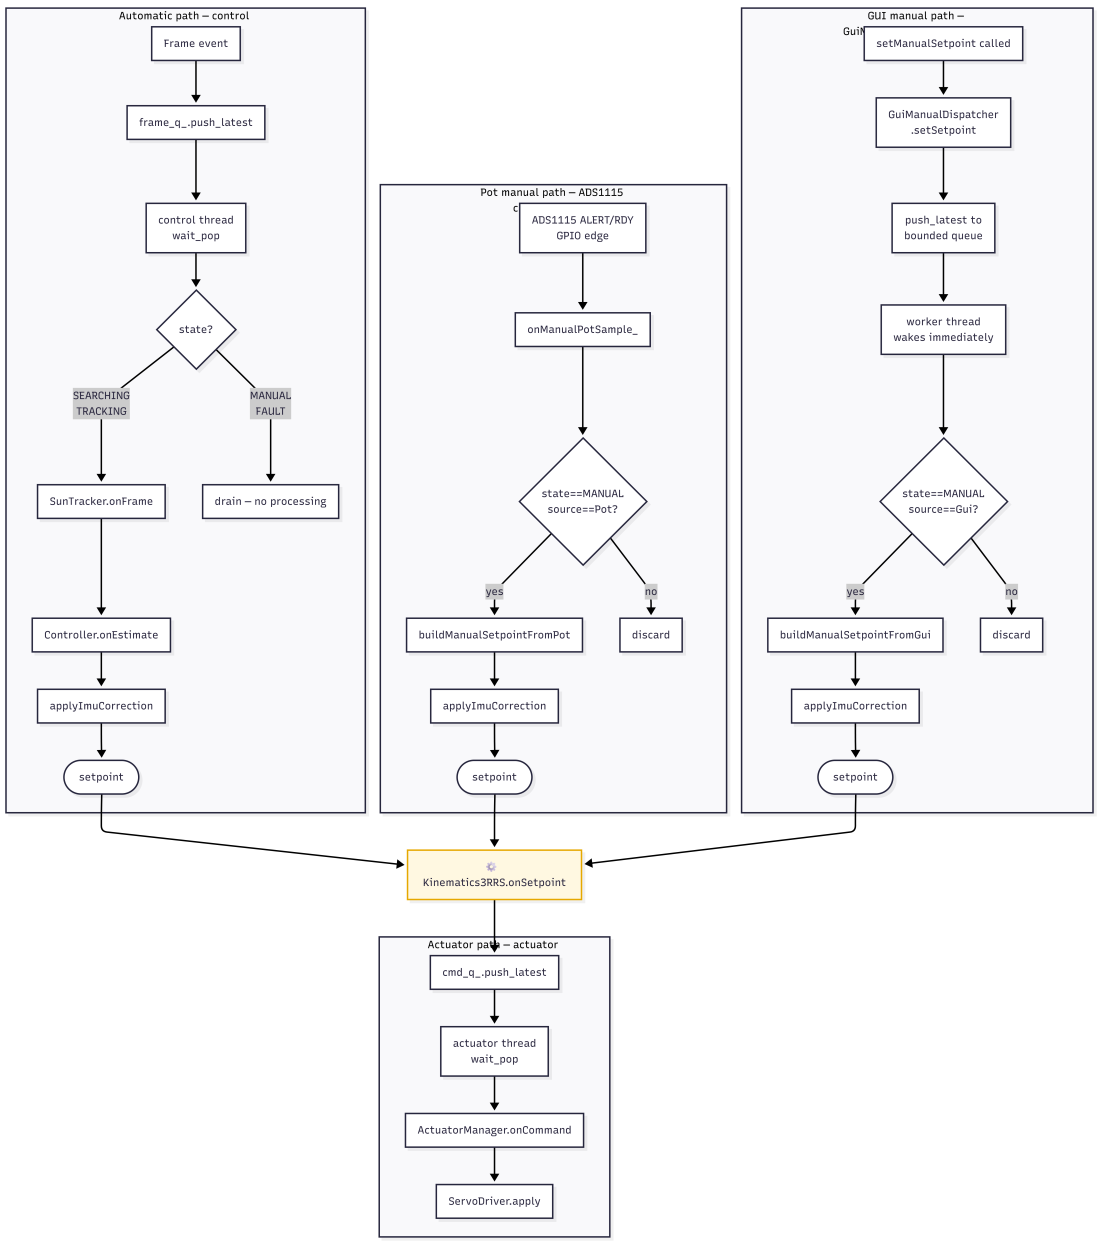
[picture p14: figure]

Figure 8.1. Automatic vs manual processing paths — thread boundaries, state-conditional branching in the control thread, and convergence at Kinematics3RRS.

## 9. Dataflow and Control Pipelines

### 9.1 Automatic Path (control thread)

Camera DMA callback
→ LatencyMonitor.onCapture(frame_id, t_capture) → frame_q_.push_latest(FrameEvent)

[control thread wakes from wait_pop()]
→ SunTracker.onFrame(FrameEvent)
estimate_cb_(SunEstimate)
→ LatencyMonitor.onEstimate(frame_id, t_estimate)
→ setState(TRACKING if confidence >= threshold, else SEARCHING) → Controller.onEstimate(SunEstimate) setpoint_cb_(PlatformSetpoint)
→ LatencyMonitor.onControl(frame_id, t_control)
→ ManualImuCoordinator.applyImuCorrection(setpoint) → Kinematics3RRS.onSetpoint(corrected setpoint) command_cb_(ActuatorCommand)
→ cmd_q_.push_latest(ActuatorCommand)

[actuator thread wakes from wait_pop()]
→ ActuatorManager.onCommand(ActuatorCommand)
safe_command_cb_(safe ActuatorCommand)
→ LatencyMonitor.onActuate(frame_id, t_actuate)
→ ServoDriver.apply(command) | → | PCA9685 I2C write | → | PWM | → | Servos

### 9.2 Potentiometer Manual Path (ADS1115 callback thread)

ADS1115 ALERT/RDY GPIO edge (libgpiod, GPIO17)
→ onManualPotSample_() | → ManualImuCoordinator.buildManualSetpointFromPot()
→ applyImuCorrection() | → Kinematics3RRS → cmd_q_ → actuator thread →
ServoDriver

### 9.3 GUI Manual Path (GuiManualDispatcher thread)

Qt slider moved → SystemManager.setManualSetpoint(tilt, pan) → GuiManualDispatcher.setSetpoint() → queue.push_latest()

[GuiManualDispatcher thread wakes immediately]
→ ManualImuCoordinator.buildManualSetpointFromGui()
→ applyImuCorrection() → Kinematics3RRS → cmd_q_ → actuator thread → ServoDriver

### 9.4 IMU Update Path (MPU6050 callback thread)

MPU6050 INT GPIO edge (libgpiod, GPIO27)
→ Mpu6050Publisher reads 6 I2C registers
→ ManualImuCoordinator.updateImuSample()
[updates correction offset — no actuation triggered]

## 10. Software Engineering and Class Design

The class structure follows the SOLID principles — not as a checklist, but because they solve real problems in a system that combines hardware access, realtime processing, and testability.

### 10.1 Single Responsibility

Each class has one reason to change. SunTracker changes if the detection algorithm changes — it has no knowledge of servos. Controller changes if the control law changes — it has no knowledge of the Stewart mechanism geometry. Kinematics3RRS changes if the mechanism geometry changes — it has no knowledge of cameras. ServoDriver changes if PWM calibration or PCA9685 access changes — it does not implement control policy. SystemManager changes if orchestration or state machine logic changes — it does not implement vision, kinematics, or hardware access, and sits at around 380 lines.

### 10.2 Open/Closed

ICamera allows new camera backends to be added without modifying SystemManager or any downstream stage. LibcameraPublisher and SimulatedPublisher are complete, independent implementations selected at construction time in SystemFactory. ServoDriver's three startup policies (LogOnly, PreferHardware, RequireHardware) change behaviour without subclassing or branching in calling code.

### 10.3 Interface Segregation

ICamera exposes only four methods. SystemManager depends on this narrow interface, not on libcamera or OpenCV. BackendCoordinator exposes only start() and stop() to SystemManager — all I2C device construction, GPIO chip setup, and interrupt routing are internal. GuiManualDispatcher exposes only setSetpoint(), start(), and stop() — its queue and worker thread are private.

### 10.4 Dependency Inversion

The hardware abstraction layer defines the II2CDevice interface. PCA9685 depends on II2CDevice, not on LinuxI2CDevice. In tests, FakeI2CDevice is injected — PCA9685 register sequences can be verified without physical hardware. SystemManager depends on ICamera (not LibcameraPublisher), ManualImuCoordinator (not ADS1115 hardware directly), and GuiManualDispatcher (not Qt directly). SystemFactory is the only place that knows about concrete types.

### 10.5 Data Encapsulation

All mutable state is private. There are no public member variables anywhere. Incoming events are delivered through registered callbacks — nothing is exposed for external polling. Outgoing control commands use setter-style methods (onEstimate(), onSetpoint(), onCommand(), apply()). Every field accessed across threads is protected by a dedicated std::mutex, with short critical sections and copy-under-lock patterns.

### 10.6 Memory Safety

The camera backend is held as std::unique_ptr<ICamera>. Callbacks are stored as std::function. Threads are std::thread with RAII join in stop() or destructors. ThreadSafeQueue uses std::deque<T> with an explicit capacity bound. There is no raw owning pointer, no new/delete, and no malloc/free in user code.

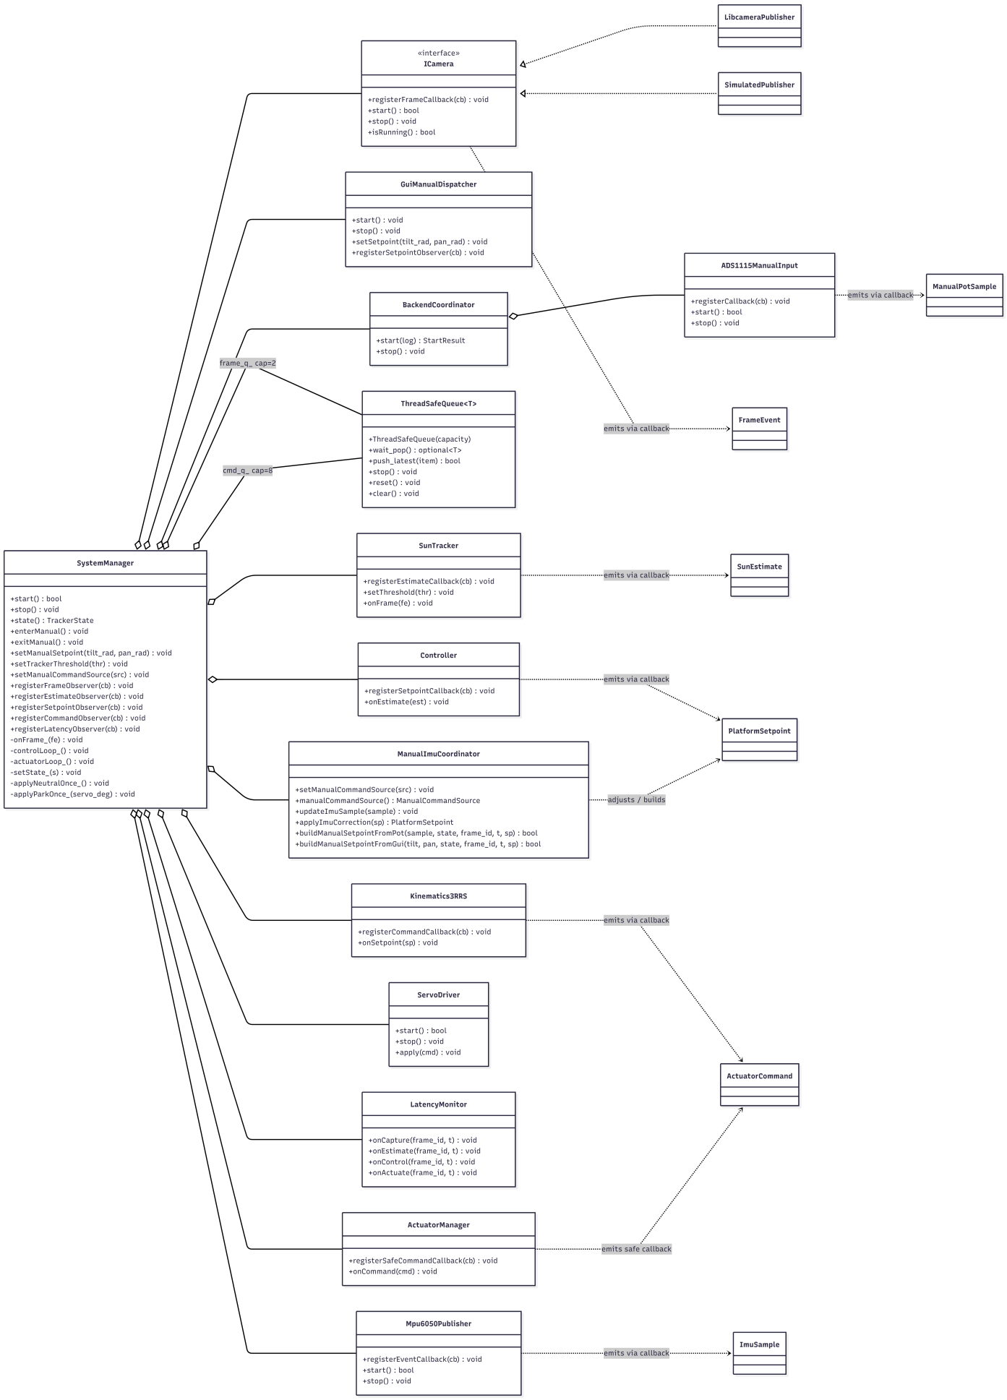
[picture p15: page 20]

Figure 10.1. UML class diagram showing interface inheritance (ICamera), composition, data-flow directions, and callback associations.

## 11. Key Source Code

This section annotates the most important code passages to show that the design described above is actually implemented that way.

### 11.1 ThreadSafeQueue — push_latest() and wait_pop()

These two methods are the core of the inter-thread handoff. push_latest() enforces the freshest-data policy. wait_pop() is where threads spend most of their time — sleeping.

bool push_latest(T item) {
{
std::lock_guard<std::mutex> lock(mutex_);
if (stopped_) { return false; }
// At capacity: drop oldest, insert newest.
if (capacity_ > 0U && queue_.size() >= capacity_) { queue_.pop_front();
}
queue_.push_back(std::move(item));
}
cv_.notify_one(); | // wake exactly one sleeping consumer
return true;
}

std::optional<T> wait_pop() {
std::unique_lock<std::mutex> lock(mutex_);
cv_.wait(lock, [this] { return stopped_ || !queue_.empty(); }); if (queue_.empty()) return std::nullopt; // woken by stop() T item = std::move(queue_.front());
queue_.pop_front();
return item;
}

The queue never grows beyond capacity. Under transient load, stale data is discarded rather than allowed to build up. stop() wakes all blocked threads cleanly so they can exit.

### 11.2 SunTracker — Weighted Centroid

The tracker scans the frame once, accumulates brightness-weighted pixel coordinates, and computes the centroid. Confidence grows with the number of pixels above threshold.

for (int y = 0; y < height; ++y) {
for (int x = 0; x < width; ++x) {
const uint8_t px = intensityAt_(frame, x, y); if (px < threshold) continue; ++bright_count;
const double w = static_cast<double>(px); weight_sum += w;
weighted_sum_x += w * x;
weighted_sum_y += w * y;
}
}
estimate.cx = weighted_sum_x / weight_sum; estimate.cy = weighted_sum_y / weight_sum;

// Confidence rises from 0 at min_pixels to 1 at 10 * min_pixels. double ratio = bright_count / (double)min_pixels; estimate.confidence = clamp((ratio - 1.0) / 9.0, 0.0, 1.0);

RGB and BGR frames are converted to luminance using integer arithmetic: (77R + 150G + 29B) >> 8. This avoids floating-point per-pixel cost. Frame validity (dimensions, stride, buffer size) is checked once before the loop.

### 11.3 Controller — Deadband with Range Re-Scaling

// Normalise pixel error to [-1, +1] relative to image centre. float ex = (est.cx - cx) / cx;
float ey = (est.cy - cy) / cy;

// Deadband: ignore small errors to prevent jitter at null.
// Re-scale the remaining range so full output authority is preserved. float applyDeadband_(float v) {
if (fabs(v) < deadband) return 0.0f;
float sign = v > 0 ? 1.0f : -1.0f;
return sign * (fabs(v) - deadband) / (1.0f - deadband); }
float pan | = clamp(k_pan | * applyDeadband_(ex), -max_pan, | max_pan);
float tilt = clamp(k_tilt * applyDeadband_(ey), -max_tilt, max_tilt);

The re-scaling step after the deadband is important. Without it, the output would jump discontinuously from 0 at the deadband edge to a small non-zero value just outside it. The re-scaling makes the transition smooth while still zeroing small errors.

### 11.4 Kinematics3RRS — Inverse Kinematics Core

// ZYX intrinsic Euler rotation matrix from (tilt_rad, pan_rad).
R = { cp, | spc*sr, | spc*cr,
0, | cr, | -sr,
-spc, cp*sr, | cp*cr | };

for each leg i:
// Rotate platform anchor into global frame, add home height. Px = R[0][0]*Px_l + R[0][1]*Py_l;
Pz = R[2][0]*Px_l + R[2][1]*Py_l + h;

// Cosine rule gives the horn angle.
C | = (dx² + dy² + dz² + L1² - L2²) / (2 * L1);
ratio = C / hypot(x, z);

if (ratio < -1 || ratio > 1) {
// Configuration unreachable — hold last valid angle. cmd.actuator_targets[i] = last_valid_deg_[i]; usedFallback = true; continue;
}

// Two geometric solutions; prefer the one closest to previous angle.
q = chooseClosest(gamma + acos(ratio), gamma - acos(ratio), q_prev_[i]); // Also prefer horn-up (cos(q) >= 0) to avoid singularities.
if (cos(q) < 0) q = otherBranch(qA, qB, q);

servo_deg = clamp(neutral_deg[i] + dir[i] * rad2deg(q), 0, 180);

Branch selection prevents discontinuous jumps between geometrically equivalent solutions as the platform moves. The ik_mtx_ mutex protects q_prev_ and last_valid_deg_ against concurrent calls from the three dispatch paths.

### 11.5 ServoDriver — Startup Policies

switch (cfg_.startup_policy) { case LogOnly:
hardware_mode_ = false; | // never try hardware — for CI
break;
case PreferHardware:
// hardware_mode_ already reflects PCA9685.start() result
break;
case RequireHardware:
if (!hardware_mode_) {
log_.error("PCA9685 required but failed to start");
return false; | // propagates to FAULT state
}
break;
}
if (cfg_.park_on_start) applyPark_(); | // safe position on every
startup

Three policies in one class cover three use cases: software testing without hardware, field deployment with graceful degradation, and production hardware with explicit failure. The policy selection avoids subclassing and keeps all servo output behaviour in one place.

## 12. Testing and Reliability

Tests sit alongside their source under src/*/tests/ and are integrated with CTest. A small custom framework (src/tests/support/) avoids an external dependency. Two tiers exist: 55 software tests that run without hardware, and 20 hardware-adjacent tests enabled with -DSOLAR_ENABLE_HW_TESTS=ON.

### 12.1 Software Test Matrix

Module Under Test | Cases Covered
SunTracker (3) | Bright pixel detection; zero confidence when no bright region; weighted centroid correctness on synthetic input.
Controller (4) | Confidence gating — no motion below threshold; deadband suppression; non-zero response outside deadband; output saturation.
Kinematics3RRS (9) | Output range for moderate setpoints; neutral symmetry; frame ID propagation; continuity for small changes; invalid geometry error surfacing; fallback to last valid; consecutive invalid configs; branch stability.
ManualInputMapper (5) | Centre-voltage zero mapping; full-range linear mapping; inversion flags; deadband re-scaling; out-of-range clamping.
ImuTiltEstimator (5) | Invalid sample handling; level orientation; positive/negative tilt reconstruction; degenerate denominator protection.
ImuFeedbackMapper (4) | Zero-tilt zero-correction; sign correctness; symmetry; runtime gain change takes effect immediately.
ActuatorManager (5) | First-command behaviour; per-channel rate limiting; saturation ordering relative to history update; history reset; zero-step hold.
ThreadSafeQueue (9) | FIFO ordering; strict bounded rejection; push_latest drop-oldest; blocking wake; stop/unblock; concurrent producer-consumer integrity; freshest-data under contention; stress test.
LatencyMonitor (3) | Ordered timestamp handling; out-of-order robustness; in-flight pruning under pressure.
SystemManager (15) | IDLE→STARTUP→SEARCHING→TRACKING progression; manual mode command emission; null-camera FAULT; camera-start FAULT; IMU shadow/disabled/live variants; state observer transitions; end-to-end pipeline; sustained multi-frame throughput; GUI manual path independence from camera frames.

Table 12.1. Software test matrix — 55 CTest entries, all runnable without hardware.

### 12.2 Hardware-Adjacent Tests

Target | Cases
PCA9685 (4) | Safe default construction; pre-start failure; channel validation; safe stop before startup.
ServoDriver (9) | LogOnly/PreferHardware/RequireHardware startup; injected PCA path; no writes while stopped; park on start/stop; channel clamping; inverted channel mapping.
Mpu6050Publisher (6) | Callback pre-condition; WHO_AM_I identity check; six init register writes; full start/stop lifecycle; double-start guard; startup discard window.
LinuxI2CDevice (1) | I2C hardware smoke path. Skips cleanly (SKIP_RETURN_CODE 77) when hardware is absent.

Table 12.2. Hardware-adjacent tests — 20 additional CTest entries enabled with -DSOLAR_ENABLE_HW_TESTS=ON.

# Run software tests (no hardware needed) ctest --test-dir build --output-on-failure

# Run hardware-adjacent tests on Raspberry Pi

SOLAR_RUN_I2C_HW_TESTS=1 ctest --test-dir build -L hw --output-on-failure

### 12.3 Fault Handling

FAULT state is entered on: null camera at startup; ServoDriver RequireHardware failure; BackendCoordinator failure; camera stream failure; invalid kinematics result at runtime. In FAULT, actuator commands are suppressed. stop() is safe from FAULT and proceeds to STOPPING → IDLE.

On both startup and shutdown, ServoDriver moves all servos to a safe park position (configurable via park_on_start and park_on_stop). This prevents the platform from being in an unknown pose when the process starts or exits.

### 12.4 Shutdown

stop() is safe from any state and can be called multiple times. The STOPPING sequence is ordered: camera.stop() → backends.stop() → GuiManualDispatcher.stop() → frame_q_.stop() and cmd_q_.stop() (notify_all() wakes any blocked threads) → control thread join → actuator thread join → neutral servo command → driver.stop() → state = IDLE.

## 13. Realtime Performance and Latency

Latency was measured on real Raspberry Pi 5 hardware with physical servos connected and moving. The goal was to get actual numbers that could inform specific architectural decisions, not just confirm the system works.

### 13.1 Measurement Platform

Parameter | Value
Hardware | Raspberry Pi 5, BCM2712, Cortex-A76 quad-core, 4 GB RAM
OS | Raspberry Pi OS (Debian Trixie), 64-bit (aarch64), kernel 6.6.51+rpt
Build | GCC 12.2.0, Release (-O2)
Camera backend | libcamera2opencv, IMX219 CSI, 640×480, RGB888, 30 fps
Servo backend | RequireHardware — physical servos connected and moving throughout
Dataset | 1367 frames over 46.6 seconds
Tool | LatencyMonitor using std::chrono::steady_clock per frame

Table 13.1. Measurement platform.

### 13.2 Results

Metric | Average (ms) | Min (ms) | Max (ms) | Jitter (ms)
L_total (end-to-end) | 2.398 | 1.870 | 4.553 | 2.683
L_vision (capture → estimate) | 2.379 | 1.860 | 4.531 | 2.672
L_control (estimate → control) | 0.0015 | 0.0005 | 0.0703 | 0.0698
L_actuation (control → actuate) | 0.0172 | 0.0086 | 0.1563 | 0.1477

Table 13.2. Measured pipeline latency over 1367 frames on Raspberry Pi 5. Raw data: artefacts/latency.csv.

### 13.3 Interpretation

Vision processing (SunTracker) dominates, accounting for 2.38 ms — 99.2% of total latency. The control and kinematics stages add only 0.0015 ms. Actuator I2C writes take 0.017 ms on average.

Average end-to-end latency of 2.40 ms is 7.3% of the 33 ms frame period at 30 fps. Worst-case 4.55 ms is 13.8%. The system never comes close to missing a frame deadline.

The frame-interval standard deviation of 4.46 ms confirms these measurements came from real camera hardware. A timerfd-driven simulated camera produces sub-millisecond interval variation. The 4.46 ms spread reflects libcamera DMA timing variation and Linux scheduler effects — genuine hardware behaviour.

### 13.4 Design Decisions Justified by These Numbers

Decision | Why the data supports it
Frame queue capacity = 2 | Average latency (2.40 ms) is well below one frame period (33 ms). A capacity of 2 absorbs a single-frame control-thread stall without blocking the camera callback. A larger capacity would allow stale frames to accumulate.

Decision | Why the data supports it
Command queue capacity = 8 | The actuator stage (0.017 ms) is about 140× faster than vision (2.38 ms). A larger command queue absorbs short bursts from kinematic output without dropping commands prematurely.
30 Hz camera frame rate | Worst-case latency (4.55 ms) is 13.8% of the frame period. A faster rate would not reduce tracking latency because vision dominates. A slower rate would reduce responsiveness.
Separate control and actuator threads | Vision jitter (average 2.38 ms, worst-case 4.55 ms) is isolated from servo writes (0.017 ms). Without this separation, servo timing would vary by the full vision processing time on every frame.
push_latest() freshest-data policy | Under transient load the queue bounds memory use and discards stale data. Without it, frames would backlog and the control loop would be tracking a past position.

Table 13.3. Five architectural decisions directly justified by the measured latency data.

### 13.5 How Latency Is Measured

// LatencyMonitor records four timestamps per frame: t_capture — frame received by onFrame_() callback t_estimate — SunTracker estimate callback fires
t_control | — control / IMU correction complete
t_actuate | — ActuatorCommand pushed to cmd_q_

// Latency definitions:
L_vision | = t_estimate - t_capture
L_control | = t_control | - t_estimate
L_actuation = t_actuate | - t_control
L_total | = t_actuate | - t_capture

// To capture a CSV on shutdown: SOLAR_LATENCY_CSV=artefacts/latency.csv ./build/solar_tracker

### 13.6 Scope of Measurements

These numbers cover the userspace software pipeline only. Not included: camera sensor exposure time, libcamera kernel DMA buffering before userspace delivery, PCA9685 PWM propagation, servo electrical response time, or mechanical settling. The system runs as a standard Linux CFS-scheduled process, not with SCHED_FIFO priority or a PREEMPT_RT kernel.

## 14. Build and Reproducibility

Target platform: Raspberry Pi OS (Debian Trixie), 64-bit (aarch64), kernel 6.6+. libgpiod v2 must be built from source because the apt package provides v1.x only, which lacks the C++ bindings required.

### 14.1 Dependencies

# Core build tools

sudo apt install -y build-essential cmake ninja-build git pkg-config

# libgpiod v2 — build from source

sudo apt install -y autoconf autoconf-archive automake libtool wget xz-utils cd /tmp && wget
https://mirrors.edge.kernel.org/pub/software/libs/libgpiod/libgpiod-2.2.2.tar.xz tar -xf libgpiod-2.2.2.tar.xz && cd libgpiod-2.2.2
./configure --prefix=/usr/local --enable-tools --enable-bindings-cxx
make -j$(nproc) && sudo make install && sudo ldconfig

# Optional: hardware camera, Qt GUI, documentation sudo apt install -y libopencv-dev libcamera-dev sudo apt install -y qtbase5-dev libqt5charts5-dev sudo apt install -y doxygen graphviz

### 14.2 Clone and Build

# Clone including submodules — do not use the GitHub ZIP

git clone --recurse-submodules \ https://github.com/Real-Time-Stewart-Solar-Tracker/Solar-Stewart-Tracker.git cd Solar-Stewart-Tracker

# Full release build (CLI + Qt GUI + all tests)

cmake -S . -B build -G Ninja -DCMAKE_BUILD_TYPE=Release cmake --build build -j

# Minimal headless build (no Qt, no libcamera)

cmake -S . -B build -G Ninja -DCMAKE_BUILD_TYPE=Release \ -DSOLAR_ENABLE_QT=OFF -DSOLAR_TRY_LIBCAMERA=OFF -DSOLAR_TRY_OPENCV=OFF cmake --build build -j

### 14.3 Run Commands

Command | Description
./build/solar_tracker | Headless CLI. Commands: manual / auto / set / threshold / quit / help.
./build/src/qt/solar_tracker_qt | Qt GUI with live camera preview, actuation charts, manual sliders.
ctest --test-dir build --output-on-failure | Run all 55 software CTest entries.
./scripts/test_pi_hw.sh | Run hardware-adjacent tests on connected Raspberry Pi.
SOLAR_LATENCY_CSV=artefacts/latency.csv ./build/solar_tracker | Run and export latency CSV on shutdown.
doxygen Doxyfile | Generate API documentation to docs/html/.

Table 14.1. Run commands. Hardware mode requires I2C devices connected and visible on /dev/i2c-1.

### 14.4 Repository Structure

src/
actuators/ | PCA9685, ServoDriver, ActuatorManager + tests/
app/ | Application, LinuxEventLoop, CliController, SystemFactory,
AppConfig
common/ | ThreadSafeQueue, LatencyMonitor, Logger, Types
control/ | Controller, Kinematics3RRS, ManualImuCoordinator,
ManualInputMapper, ImuTiltEstimator, ImuFeedbackMapper + tests/
hal/ | II2CDevice, LinuxI2CDevice + tests/
qt/ | MainWindow, Qt entry point
sensors/ | LibcameraPublisher, SimulatedPublisher,
ADS1115ManualInput, Mpu6050Publisher + tests/
system/ | SystemManager, BackendCoordinator, GuiManualDispatcher + tests/
vision/ | SunTracker + tests/
diagrams/ | Circuit diagram, UML, architecture, state machine diagrams
mechanical model/ | SolidWorks 3-RRS CAD assembly
docs/ | system_architecture, realtime_analysis, latency_measurement,
testing, solid_justification, requirements, BOM, hardware_connections, build_and_run, REPRODUCIBILITY
artefacts/ | latency.csv — measured on Raspberry Pi 5 hardware
external/ | libcamera2opencv, libgpiod_event_demo (git submodules)
scripts/ | build_core, build_pi_debug, test_core, test_pi_hw,
run_latency, build_docs, package_release .github/workflows/ ci.yml, doxygen.yml, pi-hardware-tests.yml, release.yml

## 15. Project Management and Revision Control

### 15.1 Team Responsibilities

Name | ID | Area of Responsibility
Fadi Halteh | 3127931H | System architecture design. Runtime orchestration (SystemManager, BackendCoordinator, GuiManualDispatcher). IMU and ADS1115 event-driven integration. State machine design. All technical architecture diagrams.
Jichao Wang | 3137140W | 3-RRS inverse kinematics solver (Kinematics3RRS). Application factory (SystemFactory). Configuration (AppConfig). Entry point structure.
Ziming Yan | 2429452Y | Vision subsystem (SunTracker). Qt GUI (MainWindow, live camera preview, per-channel charts, manual sliders).
Tareq A M Almzanin | 3139787A | Control layer (Controller closed-loop logic, proportional control, deadband, manual override). Shared data type definitions.
Zhenyu Zhu | 3099498Z | Low-level actuator interface (PCA9685, ServoDriver). Latency instrumentation (LatencyMonitor). Timing analysis and CSV export.

### 15.2 Development Workflow

Development used GitHub Milestones to track major deliverables, Issues for individual tasks and bugs, Pull Requests for code review and integration, and tagged Releases for stable snapshots. Branches followed a feature/<topic> or fix/<topic> naming convention.

Every pull request required: a description of what changed and why, a note on how it was tested, and confirmation that the realtime path introduces no polling loops or sleep-based timing.

### 15.3 CI/CD

Workflow | Action
ci.yml | Every push: cmake Release build + 55 software CTest entries. Status badge in README.
doxygen.yml | Merge to main: generate Doxygen HTML and deploy to GitHub Pages.
pi-hardware-tests.yml | Tagged push: build and run hardware-adjacent tests on self-hosted Raspberry Pi runner.
release.yml | Tag push: package binary, docs, and latency CSV as a release artefact.

Table 15.1. GitHub Actions CI/CD workflows.

## 16. Limitations and Future Improvements

Area | Current Limitation
Latency scope | Measurements cover userspace software only. Camera exposure time, kernel DMA latency, servo electrical response, and mechanical settling are not measured. Angular tracking error against a reference was not quantified.
Vision robustness | SunTracker uses brightness thresholding only. In partially cloudy or high-glare conditions, multiple bright patches produce erratic centroid estimates. There is no temporal filtering or multi-region selection.
IMU live feedback | The IMU live-correction loop was not characterised for stability margins. The default deployment uses Shadow mode, which logs IMU data but does not apply correction. Combined gain interactions between the proportional controller and the IMU correction are not analytically bounded.
OS scheduling | The system runs as a standard Linux CFS-scheduled process. No SCHED_FIFO priority or PREEMPT_RT kernel was applied. Worst-case wakeup latency from other processes on the system is not bounded in software.
Kinematic calibration | Geometric parameters are set manually. Physical assembly tolerances introduce a static positioning error that is not corrected at runtime.
Energy measurement | No solar panel or power measurement circuit was included. The energy-yield improvement over a fixed panel was not quantified.

Table 16.1. Known limitations.

### 16.2 Recommended Next Steps

- Apply SCHED_FIFO scheduling to the control and actuator threads via sched_setscheduler() to bound worst-case wakeup latency under system load.
- Add temporal filtering — for example, an exponential moving average on the centroid — and multi-region selection in SunTracker to handle partial cloud cover.
- Characterise the IMU live-correction loop for stability before enabling it by default. Compute the combined loop gain and verify stability margins.
- Add per-servo position encoders or hall-effect sensors to close the kinematic calibration loop at runtime.
- Include a pyranometer and a panel current/voltage measurement to quantify energy-yield improvement against a fixed-panel baseline.
- Extend latency measurement to include PCA9685 I2C write duration and servo step response for a complete end-to-end timing picture.
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

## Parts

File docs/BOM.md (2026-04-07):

# Bill of Materials (BOM) — Solar Stewart Tracker

## 1. Hardware Components

| Item No. | Component | Specification / Model | Qty | Supplier | Unit Cost (£) | Total (£) | Notes |
|---|---|---|-----|---|---|---|---|
| 1 | Raspberry Pi 5 | 8GB Model | 1 | Lab / Personal | 80.00 | 80.00 | Main controller |
| 2 | IMX219 Camera | 8MP CSI Camera Module | 1 | Amazon | 25.00 | 25.00 | Vision input |
| 3 | PCA9685 PWM Driver | 16-channel I2C PWM | 1 | Amazon | 12.00 | 12.00 | Servo control |
| 4 | High-Torque Servo | RDS3230 or equivalent | 3 | Amazon | 15.00 | 45.00 | 3RRS actuators |
| 5 | External Power Supply | 5–6V High Current | 1 | Amazon | 20.00 | 20.00 | Servo supply |
| 6 | Breadboard & Wiring | Jumper wires, headers | 1 set | Lab | 10.00 | 10.00 | Prototyping |
| 7 | Structural Frame | Acrylic / 3D Printed | 1 | Self-fabricated | 15.00 | 15.00 | Platform support |
| 8 | Fasteners & Mounts | Screws, brackets | Assorted | Hardware Store | 10.00 | 10.00 | Mechanical assembly |

---

## 2. Software Dependencies

| Software | Purpose | Cost |
|---|---|---|
| C++17 | Core implementation | Free |
| CMake | Build system | Free |
| OpenCV | Vision processing | Free |
| libcamera | Camera backend (Pi) | Free |
| GitHub | Version control | Free |

---

## 3. Cost Summary

| Category | Cost (£) |
|---|---|
| Electronics | 182.00 |
| Mechanical | 25.00 |
| Miscellaneous | 10.00 |
| **Total Hardware Cost** | **£217.00** |

---

## 4. Budget Assessment

- Total estimated cost: **£217.00**
- Major cost drivers:
  - Raspberry Pi
  - High-torque servos
  - Camera module

---

## 5. Design Considerations

- External servo power supply used to prevent brownout.
- PWM driver isolates timing from Raspberry Pi CPU.
- Modular design allows hardware substitution without software redesign.

---

## 6. Traceability to Architecture

| Subsystem | Hardware Used |
|---|---|
| Vision (T1/T2) | IMX219 Camera |
| Control (T2) | Raspberry Pi 5 |
| Actuation (T3) | PCA9685 + Servos |
| Safety Layer | ActuatorManager (software) |
| Logging | Console / File logger |

---

## 7. Reproducibility Notes

All components are commercially available.
Part numbers and specifications allow replication of the system.
Mechanical components can be 3D printed using standard PLA.

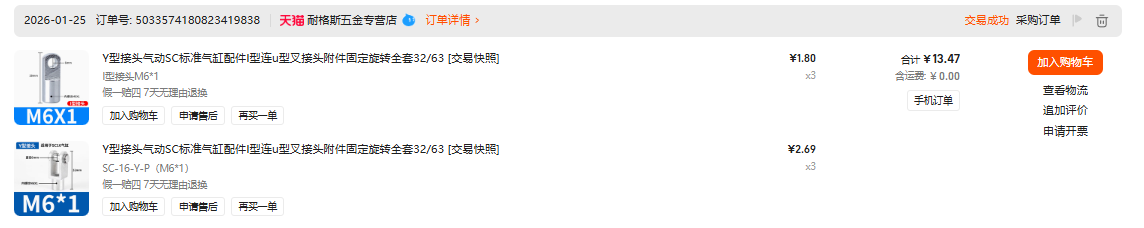
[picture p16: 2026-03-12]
datasheets/component/rotary_joint_y_sc_set.png

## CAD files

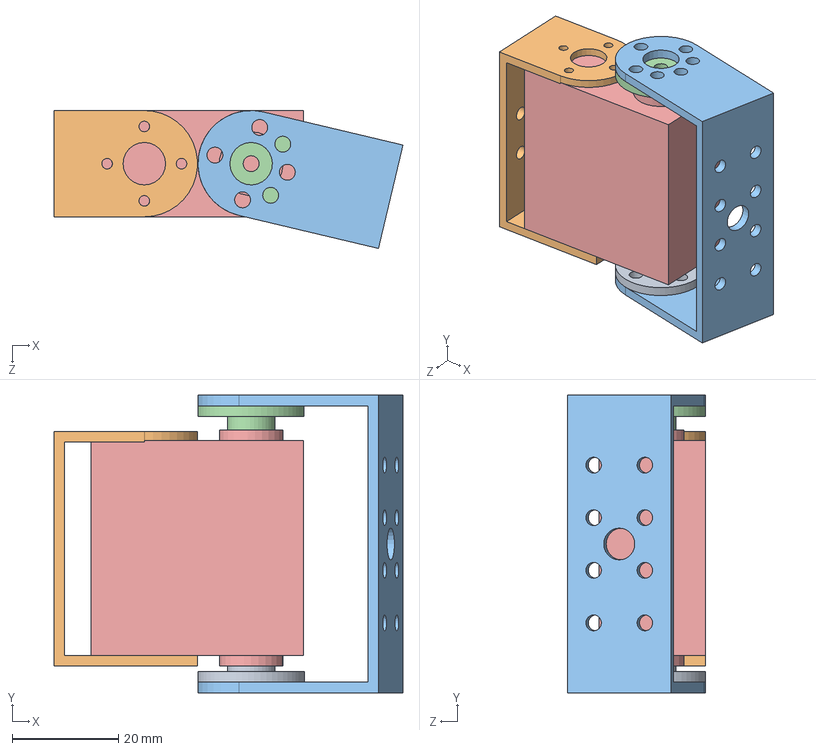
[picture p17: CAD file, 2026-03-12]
diagrams/mechanical model/3rrs/Dual-axis servo.SLDASM
65.7 x 56.0 x 26.0 mm
3230 Servo Motor
Real-axis steering wheel
Double-axis wide U bracket
Double-axis narrow U bracket
Imaginary axis steering wheel

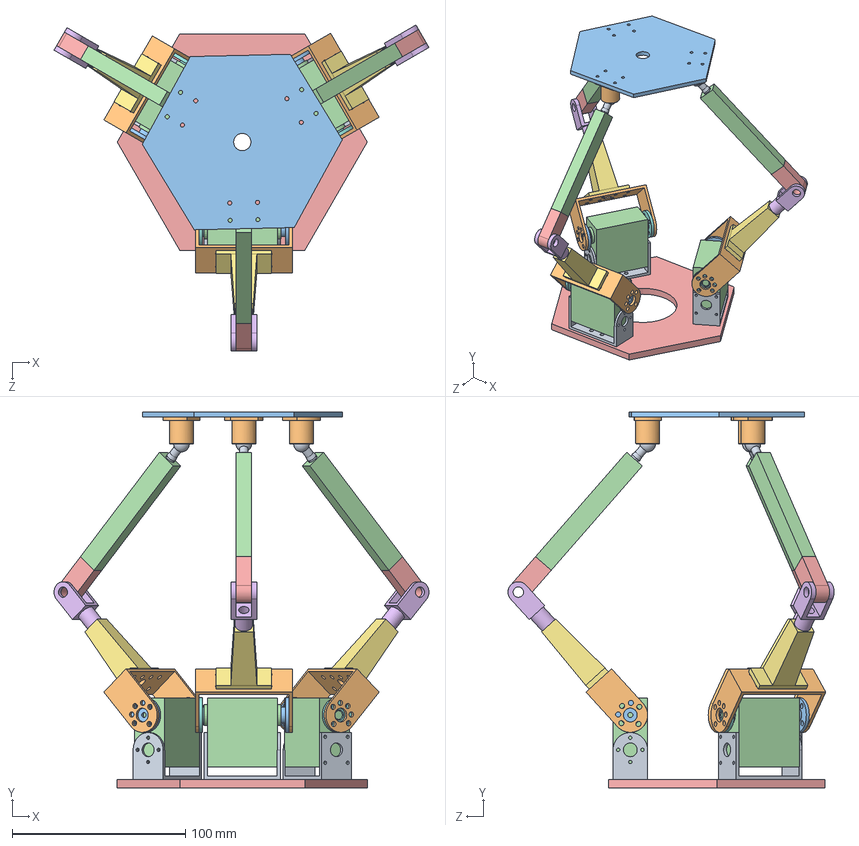
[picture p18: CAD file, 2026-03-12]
diagrams/mechanical model/3rrs/di.SLDASM
216.4 x 217.0 x 188.2 mm
The static platform below
3230 Servo Motor x 3
Real-axis steering wheel x 3
Double-axis wide U bracket x 3
Double-axis narrow U bracket x 3
Imaginary axis steering wheel x 3
L1 arm x 3
sc-16-yp x 3
I M6 x 3
L2 arm x 3
The motion platform above
ball head neck x 3
ball head x 3

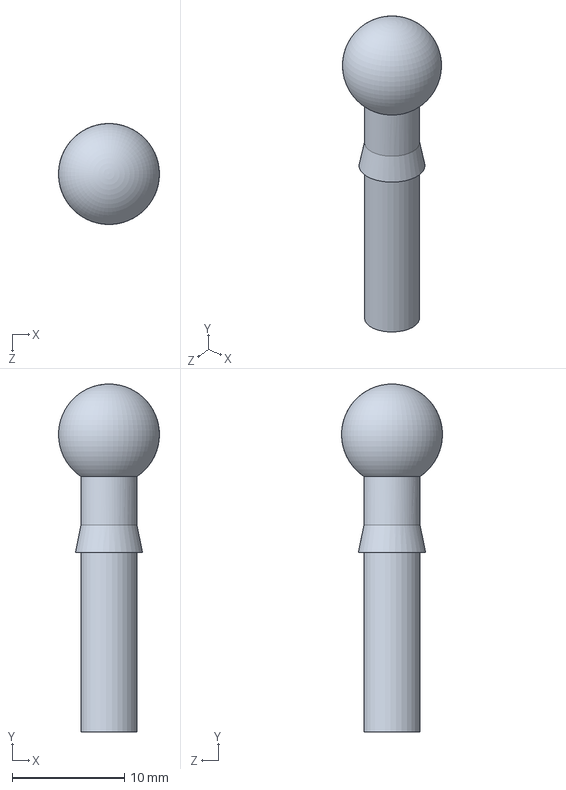
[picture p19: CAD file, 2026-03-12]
diagrams/mechanical model/3rrs/ball head.SLDPRT
8.99 x 31.0 x 8.99 mm

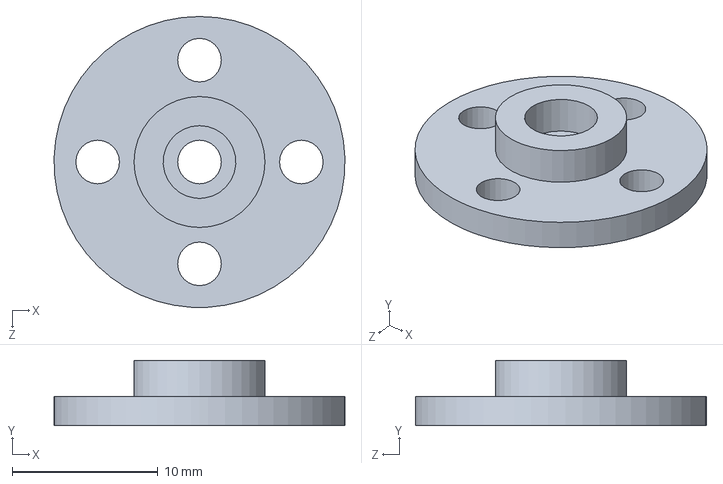
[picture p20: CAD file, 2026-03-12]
diagrams/mechanical model/3rrs/Real-axis steering wheel.SLDPRT
20.0 x 4.50 x 20.0 mm

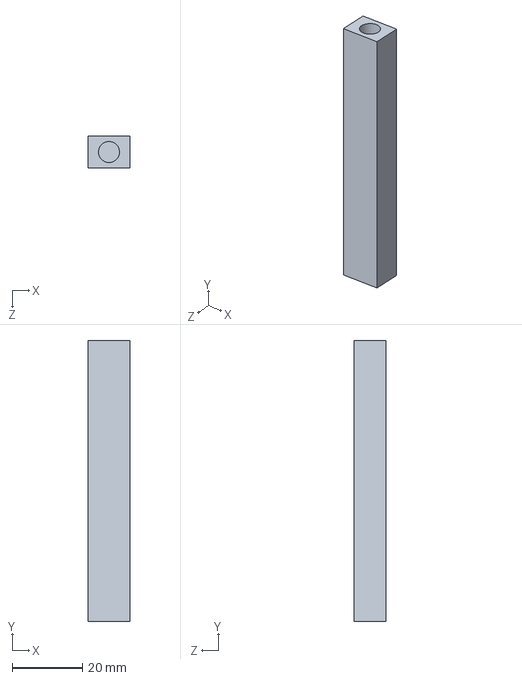
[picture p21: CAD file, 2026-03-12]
diagrams/mechanical model/3rrs/L2 arm.SLDPRT
12.0 x 80.0 x 9.00 mm

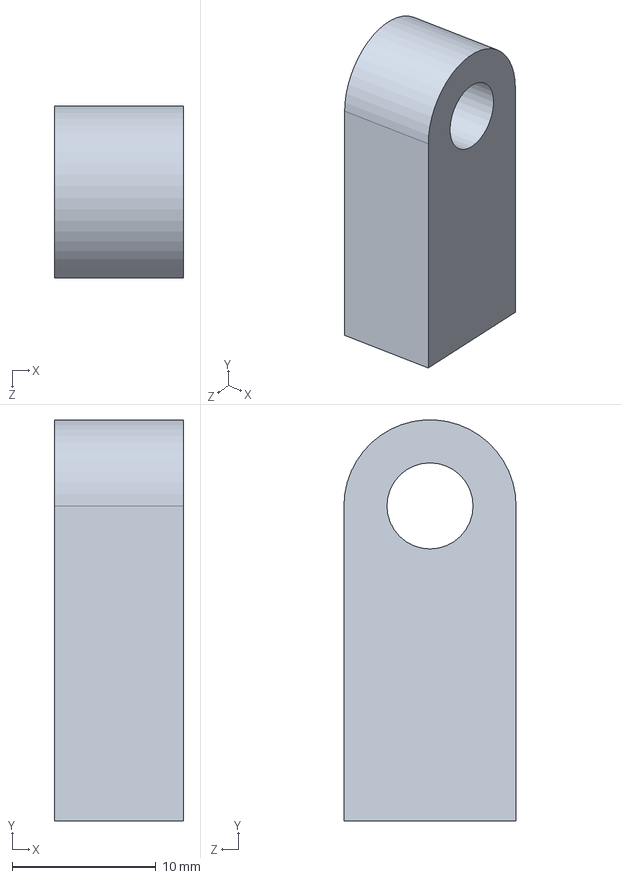
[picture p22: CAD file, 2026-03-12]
diagrams/mechanical model/3rrs/I M6.SLDPRT
9.00 x 27.9 x 12.0 mm

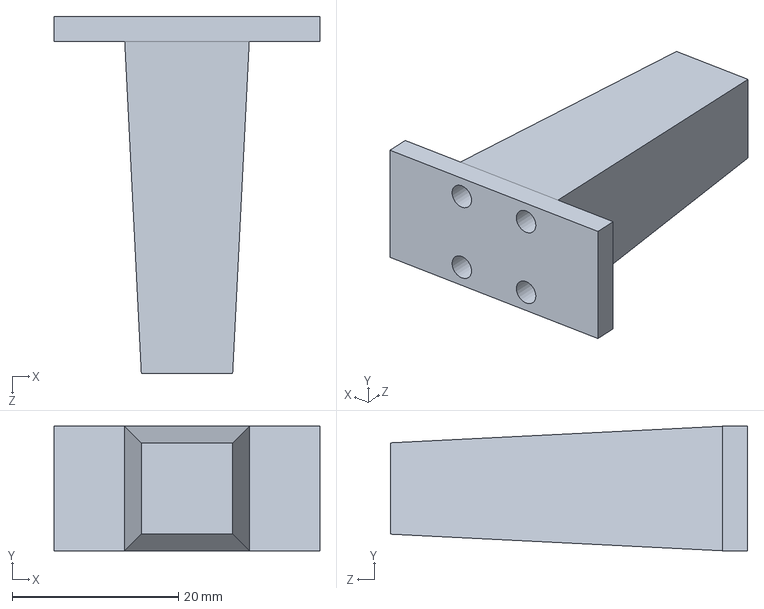
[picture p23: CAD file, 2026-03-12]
diagrams/mechanical model/3rrs/L1 arm.SLDPRT
32.0 x 15.0 x 43.0 mm

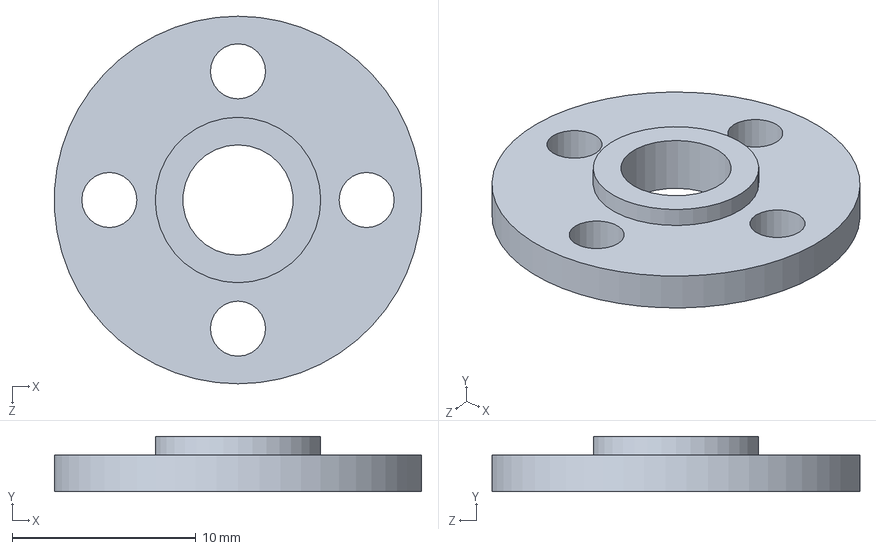
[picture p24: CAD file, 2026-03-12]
diagrams/mechanical model/3rrs/Imaginary axis steering wheel.SLDPRT
20.0 x 3.00 x 20.0 mm

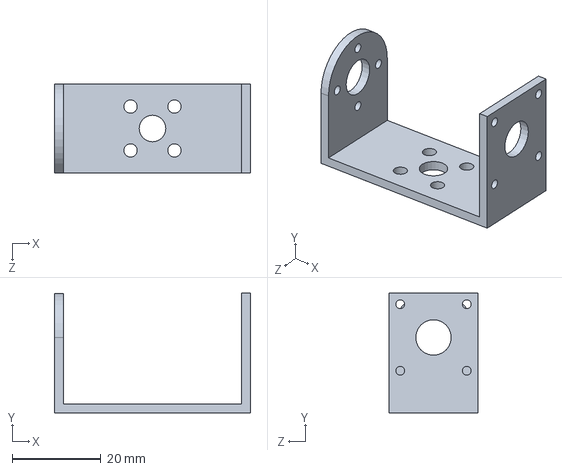
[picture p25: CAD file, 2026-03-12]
diagrams/mechanical model/3rrs/Double-axis narrow U bracket.SLDPRT
44.2 x 27.0 x 20.0 mm

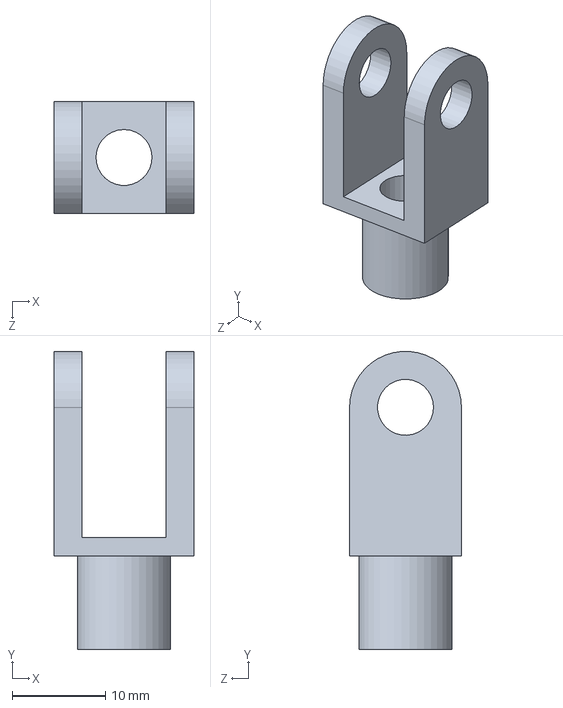
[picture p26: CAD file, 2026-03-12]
diagrams/mechanical model/3rrs/sc-16-yp.SLDPRT
15.0 x 31.9 x 12.0 mm

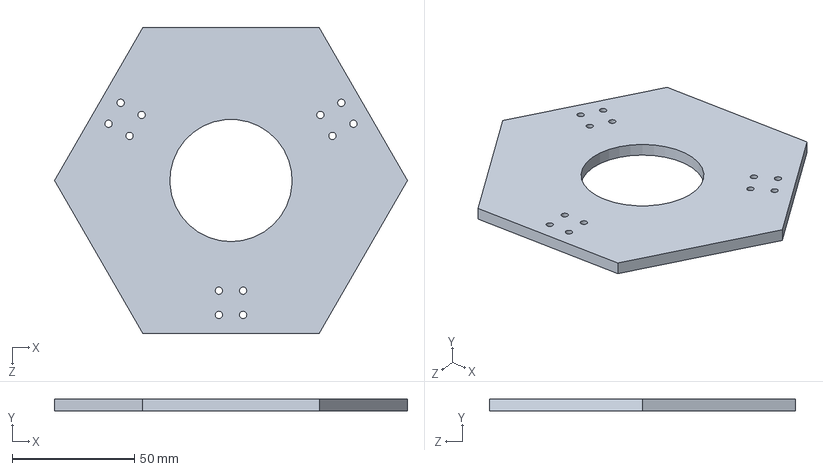
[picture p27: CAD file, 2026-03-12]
diagrams/mechanical model/3rrs/The static platform below.SLDPRT
144.3 x 5.00 x 125.0 mm

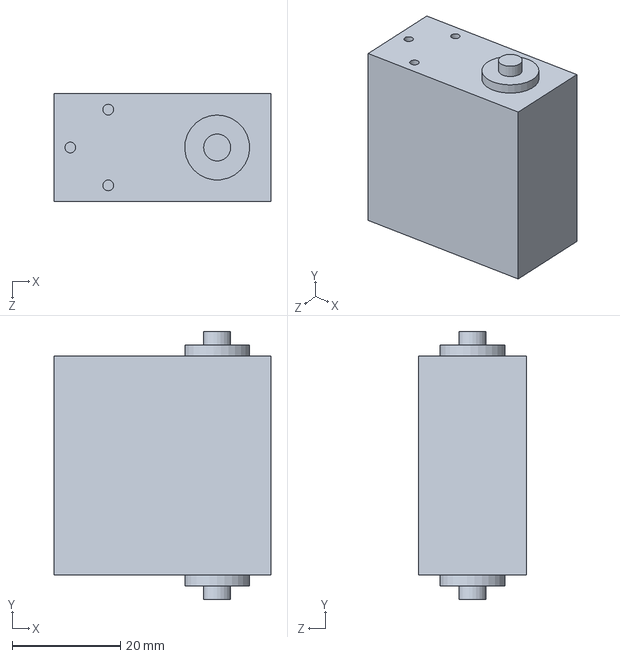
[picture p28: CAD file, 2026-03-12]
diagrams/mechanical model/3rrs/3230 Servo Motor.SLDPRT
40.0 x 49.5 x 20.0 mm

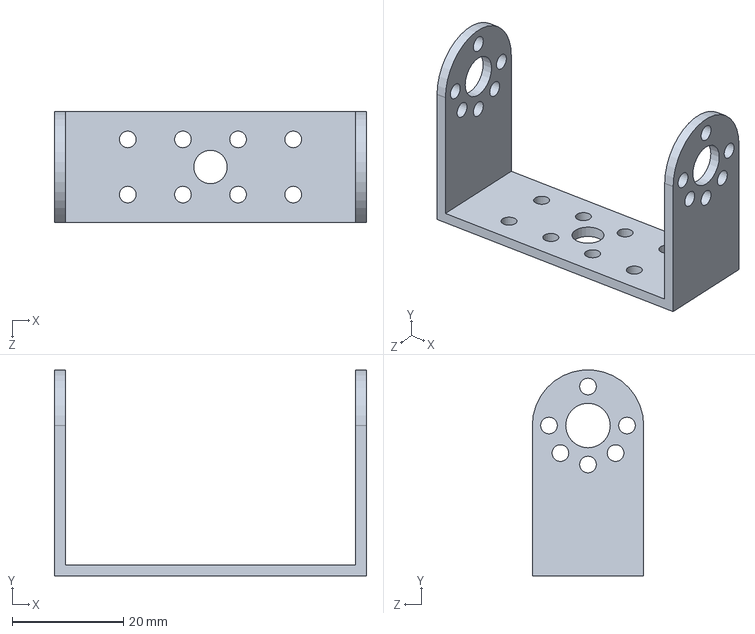
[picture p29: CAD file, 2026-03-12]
diagrams/mechanical model/3rrs/Double-axis wide U bracket.SLDPRT
56.0 x 37.0 x 20.0 mm

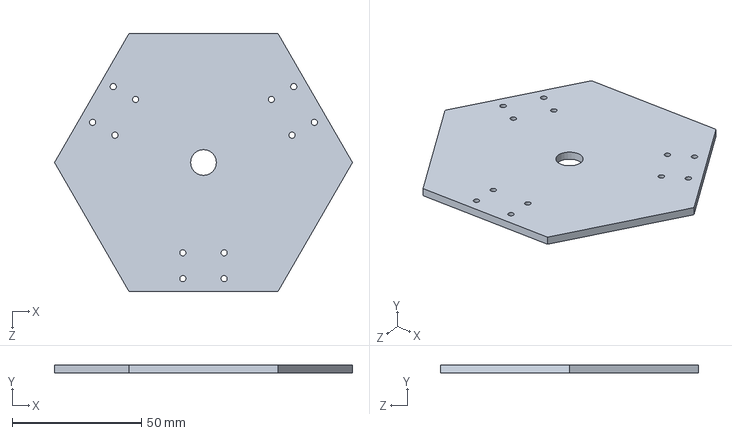
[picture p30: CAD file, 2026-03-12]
diagrams/mechanical model/3rrs/The motion platform above.SLDPRT
115.5 x 3.00 x 100.0 mm

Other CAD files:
diagrams/mechanical model/3rrs/Raspberry Pi box sketch version.SLDPRT
diagrams/mechanical model/3rrs/ball head neck.SLDPRT

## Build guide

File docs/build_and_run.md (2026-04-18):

# Build and Run

This file gives the exact repository setup, submodule checkout, build, test, and run commands for the  project .

---

## Cloning

To clone with all submodules in one step, run:

```bash
git clone --recurse-submodules https://github.com/Real-Time-Stewart-Solar-Tracker/Solar-Stewart-Tracker.git
cd Solar-Stewart-Tracker
```

If you already cloned without submodules, run:

```bash
git submodule update --init --recursive
```

---

## External repositories used by this project

The project uses these external repositories as git submodules under `external/`, use these commands if you dont have them:

```bash
git submodule add https://github.com/berndporr/libcamera2opencv.git external/libcamera2opencv
git submodule add https://github.com/berndporr/libgpiod_event_demo.git external/libgpiod_event_demo
```

After adding them, fetch their contents with:

```bash
git submodule update --init --recursive
```

To verify they are present, run:

```bash
git submodule status
ls external
```

If you ever need to refresh them to the commits recorded by the main repository, run:

```bash
git submodule sync --recursive
git submodule update --init --recursive --checkout
```

To pull the latest remote changes for the submodules:

```bash
git submodule update --remote --recursive
```

---

## If the external folders are missing

If the repository was copied manually and the `external/` repositories are not populated, use:

```bash
git submodule update --init --recursive
```

That will place the repositories at these exact paths:

```text
external/libcamera2opencv
external/libgpiod_event_demo
```

---

## Linux dependencies

### libgpiod v2 — required, must be built from source

The project requires the C++ bindings introduced in libgpiod v2. The `apt` package on Raspberry Pi OS provides v1.x only. Build v2.2.2 from source:

```bash
sudo apt install -y autoconf autoconf-archive automake libtool wget xz-utils

cd /tmp
wget https://mirrors.edge.kernel.org/pub/software/libs/libgpiod/libgpiod-2.2.2.tar.xz
tar -xf libgpiod-2.2.2.tar.xz
cd libgpiod-2.2.2
./configure --prefix=/usr/local --enable-tools --enable-bindings-cxx
make -j$(nproc)
sudo make install
sudo ldconfig
```

Verify:
```bash
pkg-config --modversion libgpiod   # should print 2.2.2
```

### Core build dependencies

```bash
sudo apt update
sudo apt install -y build-essential cmake ninja-build git pkg-config
# Note: libgpiod-dev via apt provides v1.x only. This project requires v2.
# See the libgpiod v2 build-from-source instructions below.
```

### Optional Qt GUI dependencies

```bash
sudo apt install -y qtbase5-dev libqt5charts5-dev qt5-qmake
```

### Optional OpenCV and libcamera dependencies

```bash
sudo apt install -y libopencv-dev libcamera-dev
```

### Optional hardware tools

```bash
sudo apt install -y i2c-tools
```

### Optional documentation tools

```bash
sudo apt install -y doxygen graphviz
```

---

## CMake options used by this project

```text
SOLAR_ENABLE_TESTS=ON        default
SOLAR_ENABLE_HW_TESTS=OFF    default
SOLAR_ENABLE_QT=ON           default
SOLAR_TRY_LIBCAMERA=ON       default
SOLAR_TRY_OPENCV=ON          default
SOLAR_ENABLE_COVERAGE=OFF    default
```

---

## Standard release build

```bash
cmake -S . -B build -G Ninja -DCMAKE_BUILD_TYPE=Release
cmake --build build --parallel
```

If you do not want to use Ninja:

```bash
cmake -S . -B build -DCMAKE_BUILD_TYPE=Release
cmake --build build --parallel
```

---

## Minimal headless build

This disables the optional GUI, libcamera, and OpenCV paths:

```bash
cmake -S . -B build   -G Ninja   -DCMAKE_BUILD_TYPE=Release   -DSOLAR_ENABLE_QT=OFF   -DSOLAR_TRY_LIBCAMERA=OFF   -DSOLAR_TRY_OPENCV=OFF

cmake --build build --parallel
```

---

## Build with hardware tests enabled

```bash
cmake -S . -B build   -G Ninja   -DCMAKE_BUILD_TYPE=Debug   -DSOLAR_ENABLE_TESTS=ON   -DSOLAR_ENABLE_HW_TESTS=ON   -DSOLAR_ENABLE_QT=OFF   -DSOLAR_TRY_LIBCAMERA=OFF   -DSOLAR_TRY_OPENCV=OFF

cmake --build build --parallel
```

This same configuration is also wrapped by the repository helper script:

```bash
./scripts/build_pi_debug.sh build
```

---

## Main executables

After a successful build, the main runtime targets are:

```text
build/solar_tracker
build/src/qt/solar_tracker_qt   (only if Qt5 Widgets and Qt5 Charts were found)
```

---

## Run the application

### Headless application

```bash
./build/solar_tracker
```

### Qt GUI application

```bash
./build/src/qt/solar_tracker_qt
```

---

## Run the software tests

```bash
ctest --test-dir build --output-on-failure
```

Repository helper script:

```bash
./scripts/test_core.sh build
```

---

## Run hardware-labelled tests on Raspberry Pi

The helper script sets default hardware environment variables and then runs CTest with the `hw` label.

```bash
./scripts/test_pi_hw.sh build
```

Equivalent explicit form:

```bash
export SOLAR_RUN_CAMERA_HW_TESTS=1
export SOLAR_RUN_I2C_HW_TESTS=1
export SOLAR_I2C_DEV=/dev/i2c-1
ctest --test-dir build -L hw --output-on-failure
```

---

## Manual hardware smoke tests

These are for controlled hardware checks and should only be run on the target machine with the hardware connected safely.

```bash
./build/src/actuators/tests/test_pca9685
./build/tests/test_servodriver
```

---

## Typical Raspberry Pi workflow

```bash
git clone --recurse-submodules https://github.com/Real-Time-Stewart-Solar-Tracker/Solar-Stewart-Tracker.git
cd Solar-Stewart-Tracker

git submodule update --init --recursive

cmake -S . -B build   -G Ninja   -DCMAKE_BUILD_TYPE=Release   -DSOLAR_ENABLE_QT=OFF   -DSOLAR_ENABLE_HW_TESTS=ON

cmake --build build --parallel

ctest --test-dir build --output-on-failure
./build/solar_tracker
```

---

## Clean rebuild

If the build directory becomes stale, rebuild from scratch:

```bash
rm -rf build build
git submodule sync --recursive
git submodule update --init --recursive
cmake -S . -B build -G Ninja -DCMAKE_BUILD_TYPE=Release
cmake --build build --parallel
ctest --test-dir build --output-on-failure
```

---

## Notes

- Use `--recurse-submodules` on the first clone so the external repositories are checked out immediately.
- If someone cloned the repository without submodules, `git submodule update --init --recursive` is the required recovery step.
- Keep the external repositories at the paths under `external/` so the build system can find them consistently.

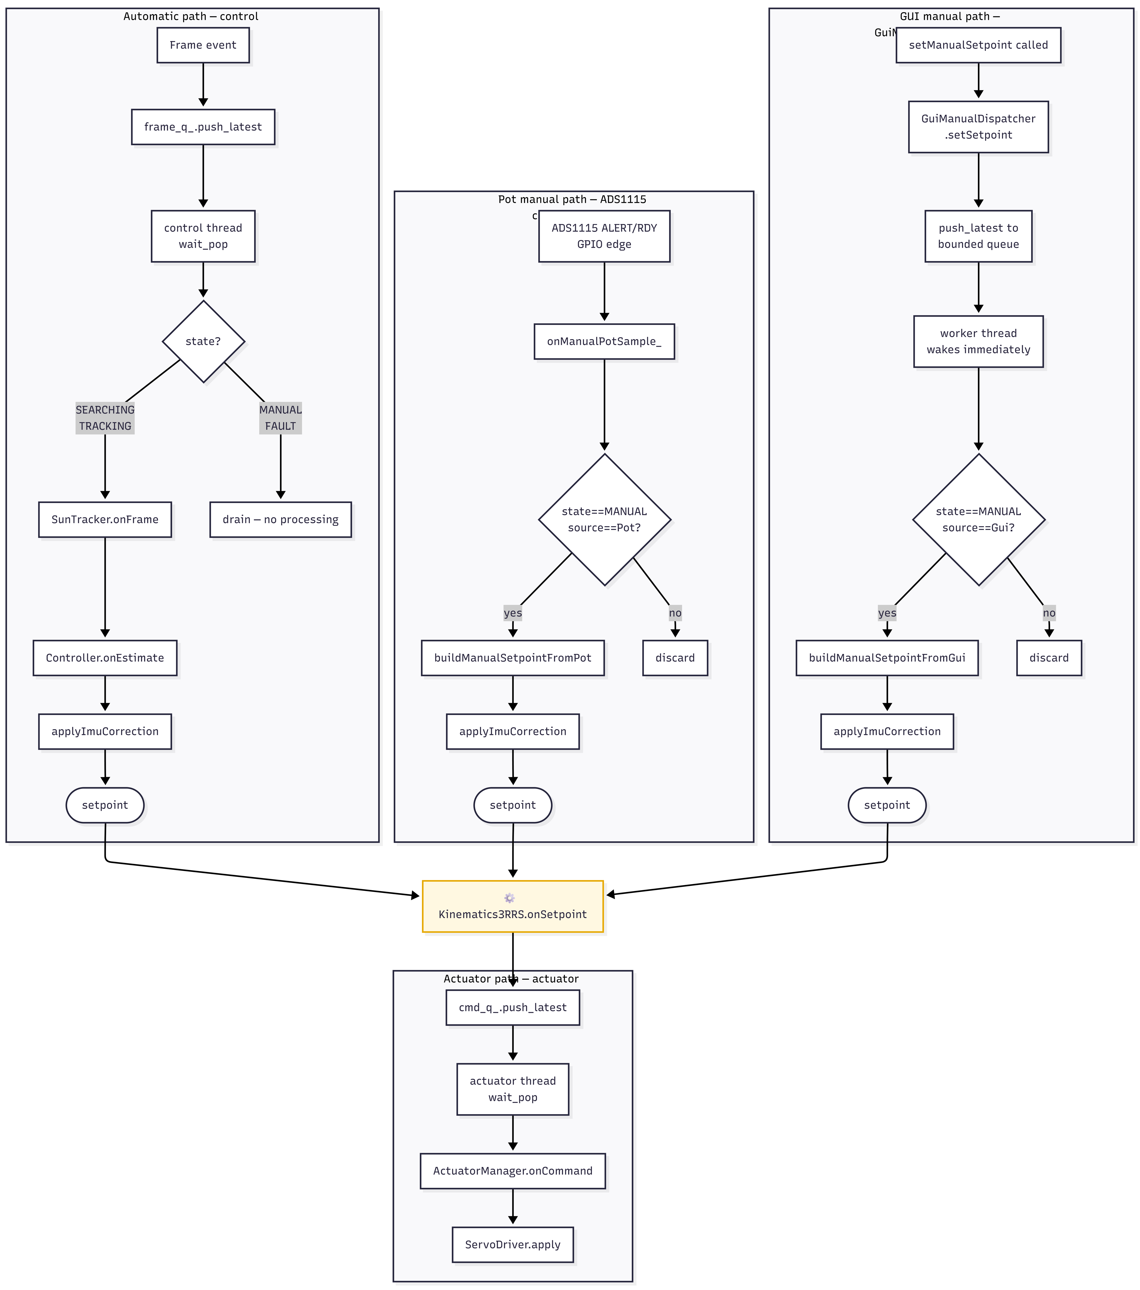
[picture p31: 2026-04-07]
diagrams/Automatic Processing vs Manual Processing.png

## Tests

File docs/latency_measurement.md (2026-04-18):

# Realtime Latency Measurement and Evidence

This document presents quantitative evidence for the software-side latency of the system, measured on real hardware using the physical camera backend.

The measured processing path is:

**Camera → FrameQueue → SunTracker → (state-dependent Controller) → ManualImuCoordinator → Kinematics3RRS → ActuatorManager → ServoDriver**

Latency data is collected at runtime using monotonic timestamps and written to `artefacts/latency.csv`.

---

## 0. Measurement Platform

| Parameter | Value |
|---|---|
| Hardware | Raspberry Pi 5 (BCM2712, Cortex-A76, 4-core, 4 GB RAM) |
| Operating system | Raspberry Pi OS (Debian Trixie), 64-bit (aarch64) |
| Kernel | Linux 6.6.51+rpt-rpi-2712 (aarch64) |
| Compiler | GCC 12.2.0 (aarch64-linux-gnu) |
| Build type | Release (`-O2`) |
| Camera backend | libcamera2opencv (IMX219 CSI, 640×480, RGB888, 30 fps) |
| Servo backend | ServoDriver::StartupPolicy::RequireHardware |
| Frames captured | 1367 |
| Run duration | 46.6 seconds |

---

## 1. Measured Results

Measurement extracted from runtime output:

- Frames processed: 1367
- Data source: LatencyMonitor summary

| Metric | Average (ms) | Minimum (ms) | Maximum (ms) | Jitter (ms) |
|---|---:|---:|---:|---:|
| **L_total** | **2.397656** | 1.869860 | 4.553350 | 2.683490 |
| L_vision (capture to estimate) | 2.379005 | 1.859520 | 4.531040 | 2.671520 |
| L_control (estimate to control) | 0.001495 | 0.000500 | 0.070347 | 0.069847 |
| L_actuation (control to actuate) | 0.017155 | 0.008648 | 0.156285 | 0.147637 |

---

## 2. Frame-Interval Analysis

The following frame-arrival statistics confirm that the measurement was performed using the real camera backend rather than the synthetic timer-driven simulator.

| Metric | Value |
|---|---|
| Mean frame interval | 34.15 ms |
| Frame interval standard deviation | 4.46 ms |
| Minimum frame interval | 31.20 ms |
| Maximum frame interval | 66.78 ms |
| Effective frame rate | 29.3 fps |

A `timerfd`-driven simulated backend produces frame intervals with sub-millisecond standard deviation and negligible jitter. The measured standard deviation of 4.46 ms and the 35.6 ms jitter range are consistent with real camera sensor readout variation, libcamera DMA buffer completion timing, and kernel scheduling effects. This confirms that the latency data reflects genuine hardware-in-the-loop operation.

---

## 3. Pipeline Interpretation

The latency measurements correspond to the following stages:

- **L_vision** — frame arrival to SunTracker output; includes frame handling and vision processing
- **L_control** — Controller and ManualImuCoordinator; includes state-dependent execution (skipped in MANUAL)
- **L_actuation** — Kinematics3RRS to ActuatorManager to ServoDriver
- **L_total** — full path from frame reception to actuator command issuance

---

## 4. Timestamp Strategy

Timestamps are recorded using `std::chrono::steady_clock`. Per frame:

```cpp
t_capture  — frame received
t_estimate — SunTracker output
t_control  — control / coordination complete
t_actuate  — actuator command issued
```

All timestamps are associated with a frame identifier and stored until the full pipeline completes.

---

## 5. Latency Definitions

| Metric | Definition |
|---|---|
| L_vision | t_estimate minus t_capture |
| L_control | t_control minus t_estimate |
| L_actuation | t_actuate minus t_control |
| L_total | t_actuate minus t_capture |

Total latency is measured directly, not inferred.

---

## 6. Measurement Method

Latency is collected using the runtime `LatencyMonitor`:

- timestamps recorded at each pipeline stage
- per-frame data aggregated
- summary statistics computed at shutdown
- raw data exported to CSV at `artefacts/latency.csv`

Execution characteristics during measurement:

- camera produces frames via libcamera callback through libcamera2opencv
- control thread blocks on frame queue
- actuator thread blocks on command queue
- no polling or sleep-based scheduling is used in the processing path

---

## 7. Observations

### 7.1 Dominant Latency Source

- vision processing dominates total latency (average 2.38 ms)
- control stage is negligible (average 0.0015 ms)
- actuation stage is small (average 0.017 ms)

### 7.2 End-to-End Behaviour

- average latency approximately 2.40 ms
- worst-case latency approximately 4.55 ms
- jitter approximately 2.68 ms

### 7.3 Throughput Context

At 30 Hz, frame period is approximately 33 ms. Measured average latency of 2.40 ms is approximately 7.3% of one frame period, meaning:

- processing completes well before the next frame arrives
- no systematic backlog accumulation occurs
- substantial timing margin exists for transient load spikes

---

## 8. Design Decisions Informed by Measured Latency

The measured latency data directly shaped the following architectural choices.

**Frame queue capacity set to 2**

Average end-to-end latency of 2.40 ms is well below the 33 ms frame period at 30 Hz. A capacity of 2 allows the queue to absorb a brief control-thread stall without blocking the camera callback, while keeping the bound tight enough that the control thread never processes a frame more than one period old. A capacity of 1 would cause unnecessary frame drops under any transient load; a larger capacity would allow stale frames to accumulate and degrade tracking responsiveness.

**Command queue capacity set to 8**

The actuation stage (average 0.017 ms, worst case 0.16 ms) is faster than the vision stage by two orders of magnitude. The larger command queue absorbs short bursts from kinematics output without risking drops on the actuator thread, while remaining bounded enough to prevent unbounded command backlog under sustained load.

**30 Hz camera frame rate**

Worst-case measured pipeline latency of 4.55 ms is approximately 13.8% of a 33 ms frame period. This margin is sufficient for tracking a slowly moving solar target and confirms that 30 Hz is an appropriate operating rate for this application. A higher frame rate would not reduce tracking latency meaningfully given that vision processing dominates the total path.

**Separate control and actuator threads**

Vision and control stages combined (average 2.38 ms) are substantially slower than the actuation stage (average 0.017 ms). Separating these into two threads via a bounded queue ensures that vision processing jitter does not introduce unnecessary delay into the servo output path. The actuator thread processes commands as soon as they arrive rather than waiting for the next vision cycle.

---

## 9. Scope of Measurement

The measurements cover software-side latency only.

Excluded from measurement:

- camera sensor exposure time
- kernel buffering before userspace delivery
- servo mechanical response time
- physical platform motion and settling
- environmental disturbances

The results represent userspace processing latency from frame arrival to actuator command issuance.

---

## 10. Summary

| Metric | Value |
|---|---|
| Average end-to-end latency | approximately 2.40 ms |
| Worst-case end-to-end latency | approximately 4.55 ms |
| Jitter | approximately 2.68 ms |

The system demonstrates consistent end-to-end processing with bounded latency and no accumulation. The dominant cost lies in the vision stage with minimal overhead in control and actuation. The pipeline architecture — frame queue capacity 2, command queue capacity 8, 30 Hz frame rate, dual worker threads — is directly supported by the measured timing evidence presented above. All measurements were taken on real hardware using the libcamera2opencv backend with an IMX219 sensor at 640×480 resolution.

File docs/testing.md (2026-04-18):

# Testing and Reliability Strategy

This document describes the testing setup implemented in the repository source. Tests are co-located with their modules under `src/*/tests/` and wired into CTest via each module's own `CMakeLists.txt`.

The test approach is intentionally lightweight:

- a small custom runner is used instead of an external framework
- named checks are registered with CTest via each module's `CMakeLists.txt`
- core logic is exercised with deterministic inputs
- hardware-adjacent tests are separated behind an explicit build option
- fake I2C support is used where that improves automation

---

## 1. Testing Approach

The test strategy is based on the following principles:

- keep core logic testable without physical hardware
- isolate vision, control, queueing, kinematics, and system state as deterministic software tests
- make hardware-adjacent tests opt-in via `-DSOLAR_ENABLE_HW_TESTS=ON`
- expose individual named cases through CTest
---

## 2. Test Framework

The repository does not use GoogleTest, Catch2, or another external framework. Instead it uses a small custom framework at `src/tests/support/`:

| File | Purpose |
|---|---|
| `src/tests/support/test_main.cpp` | Runner entry point |
| `src/tests/support/test_common.hpp` | `TEST_CASE(...)` registration and `REQUIRE(...)` assertion helper |
| `src/tests/support/FakeI2CDevice.hpp` | Fake I2C device for hardware-adjacent software tests |

Each test executable is built by linking `test_main.cpp` together with one or more test source files.

### Running an executable directly

```bash
# Run all tests compiled into an executable
./build/src/control/tests/test_control
```

With no arguments an executable runs every test compiled into it. CTest remains the primary interface for selecting and running tests. Individual test binaries can also be run directly from the build tree, but their command-line interfaces are not assumed to be uniform across all executables.

---

## 3. Test Executables and Module Structure

Tests are co-located with source. Each module's `CMakeLists.txt` conditionally includes its `tests/` subdirectory.

### Always-built executables (`SOLAR_ENABLE_TESTS=ON`)

| Executable | Module | Source path |
|---|---|---|
| `test_common_core` | `src/common` | `src/common/tests/` |
| `test_vision` | `src/vision` | `src/vision/tests/` |
| `test_control` | `src/control` | `src/control/tests/` |
| `test_actuators` | `src/actuators` | `src/actuators/tests/` |
| `test_system` | `src/system` | `src/system/tests/` |

### Hardware-adjacent executables (`SOLAR_ENABLE_TESTS=ON` and `SOLAR_ENABLE_HW_TESTS=ON`)

| Executable | Module | Source path |
|---|---|---|
| `test_pca9685` | `src/actuators` | `src/actuators/tests/` |
| `test_servodriver` | `src/actuators` | `src/actuators/tests/` |
| `test_mpu6050_publisher` | `src/sensors` | `src/sensors/tests/` |
| `test_linux_i2c_hw` | `src/hal` | `src/hal/tests/` |

---

## 4. CTest Integration

CTest is used and named cases are registered with `add_test(...)` in each module's `CMakeLists.txt`, allowing failures to be reported at individual test-case level.

```bash
# Linux / single-config generators
ctest --test-dir build --output-on-failure

# Windows / multi-config generators
ctest --test-dir build -C Release --output-on-failure
```

### Test count

| Condition | CTest entries |
|---|---:|
| `SOLAR_ENABLE_TESTS=ON` only | 55 |
| `SOLAR_ENABLE_TESTS=ON` and `SOLAR_ENABLE_HW_TESTS=ON` | 75 |

---

## 5. CTest Cases by Module

### 5.1 SunTracker

Executable: `test_vision` — Source: `src/vision/tests/test_suntracker.cpp`

| CTest Case | What It Covers |
|---|---|
| `SunTracker_DetectsSingleBrightPixel` | Bright target detection |
| `SunTracker_NoBrightPixels_ProducesZeroConfidence` | Zero-confidence when no bright region exists |
| `SunTracker_WeightedCentroid_IsCorrect` | Weighted centroid on deterministic synthetic input |

### 5.2 Controller

Executable: `test_control` — Source: `src/control/tests/test_controller.cpp`

| CTest Case | What It Covers |
|---|---|
| `Controller_LowConfidence_NoMotion` | Confidence gating |
| `Controller_WithinDeadband_NoMotion` | Deadband behaviour |
| `Controller_OutsideDeadband_ProducesMotion` | Non-zero control response |
| `Controller_OutputClamped` | Output saturation/clamping |

### 5.3 Kinematics3RRS

Executable: `test_control` — Source: `src/control/tests/test_kinematics.cpp`

| CTest Case | What It Covers |
|---|---|
| `Kinematics3RRS_outputs_in_range_for_moderate_setpoint` | Output sanity and servo range |
| `Kinematics3RRS_neutral_setpoint_produces_near_neutral_angles` | Neutral symmetry |
| `Kinematics3RRS_frame_id_forwarded_through_callback` | Frame ID propagation |
| `Kinematics3RRS_small_setpoint_changes_produce_small_output_changes` | Continuity for small input changes |
| `Kinematics3RRS_zero_setpoint_after_valid_does_not_trigger_fallback` | Zero setpoint does not degrade |
| `Kinematics3RRS_large_reachable_setpoint_stays_in_range` | Workspace boundary check |
| `Kinematics3RRS_invalid_geometry_surfaces_error_status` | Invalid-geometry error surfacing |
| `Kinematics3RRS_first_invalid_then_second_invalid_stays_in_range` | Consecutive invalid configs safe |
| `Kinematics3RRS_good_then_bad_geometry_falls_back_to_last_valid` | Fallback after previously valid state |

### 5.4 ManualInputMapper

Executable: `test_control` — Source: `src/control/tests/test_manual_input_mapper.cpp`

| CTest Case | What It Covers |
|---|---|
| `ManualInputMapper_CentreVoltage_MapsToZeroCommand` | Centre mapping |
| `ManualInputMapper_LowAndHighVoltages_MapToMinusAndPlusOne` | Full-range mapping |
| `ManualInputMapper_InversionFlags_FlipDirections` | Inversion behaviour |
| `ManualInputMapper_Deadband_ZerosSmallInputsAndRescalesBeyondDeadband` | Deadband behaviour |
| `ManualInputMapper_OutOfRangeVoltages_AreClampedSafely` | Safe clamping of out-of-range inputs |

### 5.5 ImuFeedbackMapper

Executable: `test_control` — Source: `src/control/tests/test_imu_feedback_mapper.cpp`

| CTest Case | What It Covers |
|---|---|
| `ImuFeedbackMapper_ZeroTilt_ProducesZeroCorrection` | Zero-tilt response |
| `ImuFeedbackMapper_PositiveTilt_ProducesNegativeCorrection` | Correction sign |
| `ImuFeedbackMapper_NegativeTilt_ProducesPositiveCorrection` | Symmetry across tilt direction |
| `ImuFeedbackMapper_RuntimeGainChange_TakesEffectImmediately` | Immediate effect of runtime gain changes |

### 5.6 ImuTiltEstimator

Executable: `test_control` — Source: `src/control/tests/test_imu_tilt_estimator.cpp`

| CTest Case | What It Covers |
|---|---|
| `ImuTiltEstimator_InvalidSample_ReturnsZero` | Invalid sample handling |
| `ImuTiltEstimator_LevelGravity_ReturnsZeroTilt` | Level orientation |
| `ImuTiltEstimator_PositiveAx_WithGravity_ReturnsPositiveTilt` | Positive tilt reconstruction |
| `ImuTiltEstimator_NegativeAx_WithGravity_ReturnsNegativeTilt` | Negative tilt reconstruction |
| `ImuTiltEstimator_DegenerateDenominator_ReturnsZero` | Degenerate denominator protection |

### 5.7 ActuatorManager

Executable: `test_actuators` — Source: `src/actuators/tests/test_actuatormanager.cpp`

| CTest Case | What It Covers |
|---|---|
| `ActuatorManager_first_command_is_saturated_without_history_limit` | First-command behaviour |
| `ActuatorManager_subsequent_commands_are_rate_limited_per_channel` | Per-channel rate limiting |
| `ActuatorManager_saturation_happens_before_history_update` | Saturation ordering |
| `ActuatorManager_resetHistory_disables_slew_limit_for_next_command` | History reset behaviour |
| `ActuatorManager_zero_or_negative_step_holds_previous_value` | Behaviour when allowed step is zero or negative |

### 5.8 ThreadSafeQueue

Executable: `test_common_core` — Source: `src/common/tests/test_threadsafequeue.cpp`

| CTest Case | What It Covers |
|---|---|
| `ThreadSafeQueue_FIFO_basic` | FIFO ordering |
| `ThreadSafeQueue_bounded_push_strict_rejects_when_full` | Strict bounded insertion |
| `ThreadSafeQueue_bounded_push_latest_drops_oldest` | Freshest-value overwrite semantics |
| `ThreadSafeQueue_wait_pop_blocks_then_wakes` | Blocking wake-up behaviour |
| `ThreadSafeQueue_stop_unblocks_waiters_and_returns_nullopt_when_empty` | Stop/unblock behaviour |
| `ThreadSafeQueue_concurrent_producers_and_consumer_no_data_loss` | Multi-threaded data integrity |
| `ThreadSafeQueue_concurrent_wait_pop_wakes_all_consumers` | Concurrent consumer wakeup |
| `ThreadSafeQueue_push_latest_under_contention_keeps_freshest` | Freshest-data policy under contention |
| `LatencyMonitor_reports_jitter_over_multiple_records` | Jitter reporting correctness |

### 5.9 LatencyMonitor

Executable: `test_common_core` — Source: `src/common/tests/test_latency_monitor.cpp`

| CTest Case | What It Covers |
|---|---|
| `LatencyMonitor_accepts_ordered_timestamps_and_prints` | Ordered timestamp handling |
| `LatencyMonitor_handles_out_of_order_calls_without_crashing` | Out-of-order robustness |
| `LatencyMonitor_prunes_inflight_frames_under_pressure_without_crashing` | In-flight frame pruning under pressure |

### 5.10 SystemManager

Executable: `test_system`  
Sources: `src/system/tests/test_systemmanager_statemachine.cpp`, `src/system/tests/test_systemmanager_imu_shadow.cpp`

| CTest Case | What It Covers |
|---|---|
| `SystemManager_start_to_searching_then_tracking_on_bright_frame` | Startup progression and tracking-state transition |
| `SystemManager_manual_mode_emits_commands` | Manual mode command emission |
| `SystemManager_start_with_null_camera_enters_fault_and_fails` | Fault entry on null camera |
| `SystemManager_start_when_camera_start_fails_enters_fault` | Fault entry on camera start failure |
| `SystemManager_ImuShadow_StartsWithoutImuBackend` | IMU shadow-mode startup without backend |
| `SystemManager_ImuDisabled_StartsNormally` | IMU disabled mode starts normally |
| `SystemManager_ImuShadow_ManualModeTransitions` | Shadow mode does not block manual transitions |
| `SystemManager_ImuShadow_NullCameraEntersFault` | Null camera enters FAULT |
| `SystemManager_ImuShadow_CameraStartFailureEntersFault` | Camera start failure enters FAULT |
| `SystemManager_ImuShadow_StopFromIdleIsIdempotent` | Stop from IDLE is a safe no-op |
| `SystemManager_ImuLive_StartsNormallyWhenNoImuBackendConfigured` | Live mode degrades gracefully without IMU |
| `SystemManager_ImuShadow_StateObserverReceivesTransitions` | State observer receives startup transitions |
| `SystemManager_automatic_pipeline_produces_actuator_commands` | End-to-end automatic pipeline |
| `SystemManager_multiple_frames_produce_multiple_commands` | Sustained pipeline throughput |
| `SystemManager_gui_manual_produces_commands_without_camera_frames` | GUI manual path independence |
---

## 6. Hardware-Adjacent Tests (`SOLAR_ENABLE_HW_TESTS=ON`)

### 6.1 PCA9685

Executable: `test_pca9685` — Source: `src/actuators/tests/test_pca9685.cpp`

| CTest Case | What It Covers |
|---|---|
| `PCA9685_default_constructor_is_not_started` | Safe default construction |
| `PCA9685_set_pulse_us_fails_before_start` | Pre-start failure handling |
| `PCA9685_invalid_channel_rejected_even_if_not_started` | Channel validation |
| `PCA9685_stop_is_safe_when_not_started` | Safe stop before startup |

### 6.2 ServoDriver

Executable: `test_servodriver` — Source: `src/actuators/tests/test_servodriver.cpp`

| CTest Case | What It Covers |
|---|---|
| `ServoDriver_log_only_mode_starts_without_hardware` | Startup policy across hardware modes |
| `ServoDriver_require_hardware_fails_fast_when_unavailable` | Fast failure on missing required hardware |
| `ServoDriver_prefer_hardware_falls_back_to_log_only_when_unavailable` | Fallback to log-only mode |
| `ServoDriver_require_hardware_with_injected_pca_enters_hardware_mode` | Injected PCA path |
| `ServoDriver_apply_while_stopped_writes_nothing` | No writes while stopped |
| `ServoDriver_start_parks_to_neutral_when_enabled` | Parking on start |
| `ServoDriver_stop_parks_to_neutral_when_enabled` | Parking on stop |
| `ServoDriver_apply_clamps_and_writes_channels` | Command clamping and channel writes |
| `ServoDriver_inverted_channel_maps_correctly` | Inverted channel mapping |

### 6.3 Mpu6050Publisher

Executable: `test_mpu6050_publisher` — Source: `src/sensors/tests/test_mpu6050_publisher.cpp`

| CTest Case | What It Covers |
|---|---|
| `Mpu6050Publisher_StartFailsWithoutCallback` | Callback pre-condition (software) |
| `Mpu6050Publisher_StartFailsIfWhoAmIDoesNotMatch` | WHO_AM_I identity check (software) |
| `Mpu6050Publisher_InitialisesExpectedRegisters` | Six init registers written before GPIO (software) |
| `Mpu6050Publisher_StartSucceedsAndStopClosesDevice` | Full start/stop lifecycle (hardware, GPIO 27) |
| `Mpu6050Publisher_DoubleStartReturnsFalse` | Double-start guard (hardware, GPIO 27) |
| `Mpu6050Publisher_StartupDiscardPreventsEarlyCallbacks` | Startup discard window (hardware, GPIO 27) |

### 6.4 Linux I2C Hardware Check

Executable: `test_linux_i2c_hw` — Source: `src/hal/tests/test_linux_i2c_hw.cpp`

| CTest Case | Labels | Notes |
|---|---|---|
| `LinuxI2C_PCA9685_hw_init_and_write` | `hw;i2c;integration` | Skips cleanly (`SKIP_RETURN_CODE 77`) when hardware is unavailable |

---

## 7. What the Tests Demonstrate

- bright-target detection and centroid logic
- controller gating, deadband, and output clamping
- bounded queue semantics and blocking wake-up behaviour
- actuator command limiting and history behaviour
- kinematics validity, continuity, and fallback behaviour
- latency-monitor robustness
- system-manager startup, manual-mode, and selected fault paths
- manual input mapping
- IMU tilt estimation and IMU feedback mapping
- selected startup and mapping behaviour of PCA9685, ServoDriver, and MPU6050 publisher (when hardware-adjacent tests are enabled)

---

## 8. Practical Commands

```bash
# Run all CTest-registered checks
ctest --test-dir build --output-on-failure -LE hw

# Run hardware tests (requires hardware connected)
SOLAR_RUN_I2C_HW_TESTS=1 ctest --test-dir build --output-on-failure

# Run one CTest entry by name
ctest --test-dir build --output-on-failure -R Controller_OutputClamped

# Run individual module executables directly
./build/src/vision/tests/test_vision
./build/src/control/tests/test_control
./build/src/common/tests/test_common_core
./build/src/actuators/tests/test_actuators
./build/src/system/tests/test_system

# Enable and build hardware-adjacent tests
cmake -S . -B build -G Ninja -DSOLAR_ENABLE_TESTS=ON -DSOLAR_ENABLE_HW_TESTS=ON -DCMAKE_BUILD_TYPE=Debug
cmake --build build -j

# Run hardware-adjacent executables directly
./build/src/actuators/tests/test_pca9685
./build/src/actuators/tests/test_servodriver
./build/src/sensors/tests/test_mpu6050_publisher
```

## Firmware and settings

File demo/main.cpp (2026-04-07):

/**
 * @file main.cpp
 * @brief Pipeline demo — runs the full automatic tracking pipeline without hardware.
 *
 * This demo wires together the same stages used in production:
 *
 *   SimulatedPublisher → SunTracker → Controller → Kinematics3RRS
 *
 * No camera, no servos, no I²C bus required.
 * The SimulatedPublisher generates synthetic frames with a moving bright spot
 * that orbits the centre of the image. Each stage processes events and prints
 * its output so you can see the pipeline in action.
 *
 * The demo runs until interrupted by SIGINT (Ctrl+C) or SIGTERM. Shutdown is
 * handled via signalfd so the process always completes cleanly.
 *
 * Expected output (one line per frame at 30 fps):
 *
 *   [frame   1] sun=(320.0, 240.0) conf=1.00 | tilt= 0.000 pan= 0.000 | ...
 *   [frame   2] sun=(322.3, 240.0) conf=1.00 | tilt=-0.003 pan= 0.003 | ...
 *   ...
 *   ^C
 *   Demo stopped after 152 frames.
 *
 * Build with CMake (see README.md in this directory).
 */

#include "common/Logger.hpp"
#include "common/Types.hpp"
#include "control/Controller.hpp"
#include "control/Kinematics3RRS.hpp"
#include "sensors/SimulatedPublisher.hpp"
#include "vision/SunTracker.hpp"

#include <atomic>
#include <cstdio>

#include <signal.h>
#include <sys/signalfd.h>
#include <unistd.h>

int main() {
    using namespace solar;

    // -----------------------------------------------------------------------
    // 1. Logger
    // -----------------------------------------------------------------------
    Logger log;

    // -----------------------------------------------------------------------
    // 2. SimulatedPublisher
    //    Generates 640x480 frames at 30 fps with a moving bright spot.
    // -----------------------------------------------------------------------
    SimulatedPublisher::Config camCfg{};
    camCfg.width        = 640;
    camCfg.height       = 480;
    camCfg.fps          = 30;
    camCfg.moving_spot  = true;
    camCfg.noise_std    = 3.0F;
    camCfg.background   = 20U;
    camCfg.spot_value   = 240U;
    camCfg.spot_radius  = 15;
    SimulatedPublisher camera(log, camCfg);

    // -----------------------------------------------------------------------
    // 3. SunTracker
    // -----------------------------------------------------------------------
    SunTracker::Config trackerCfg{};
    trackerCfg.threshold        = 200U;
    trackerCfg.min_pixels       = 10U;
    trackerCfg.confidence_scale = 1.0F;
    SunTracker tracker(log, trackerCfg);

    // -----------------------------------------------------------------------
    // 4. Controller
    // -----------------------------------------------------------------------
    Controller::Config ctrlCfg{};
    ctrlCfg.image_width    = camCfg.width;
    ctrlCfg.image_height   = camCfg.height;
    ctrlCfg.k_pan          = 0.8F;
    ctrlCfg.k_tilt         = 0.8F;
    ctrlCfg.max_pan_rad    = 0.35F;
    ctrlCfg.max_tilt_rad   = 0.35F;
    ctrlCfg.deadband       = 0.0F;
    ctrlCfg.min_confidence = 0.4F;
    Controller controller(log, ctrlCfg);

    // -----------------------------------------------------------------------
    // 5. Kinematics3RRS
    // -----------------------------------------------------------------------
    Kinematics3RRS::Config kinCfg{};
    kinCfg.base_radius_m     = 0.20F;
    kinCfg.platform_radius_m = 0.12F;
    kinCfg.home_height_m     = 0.18F;
    kinCfg.horn_length_m     = 0.10F;
    kinCfg.rod_length_m      = 0.18F;
    kinCfg.base_theta_deg    = {120.0F, 240.0F, 0.0F};
    kinCfg.plat_theta_deg    = {120.0F, 240.0F, 0.0F};
    kinCfg.servo_neutral_deg = {90.0F, 90.0F, 90.0F};
    kinCfg.servo_dir         = {-1, -1, -1};
    Kinematics3RRS kinematics(log, kinCfg);

    // -----------------------------------------------------------------------
    // 6. Wire the pipeline with callbacks.
    //
    //    camera --> tracker --> controller --> kinematics --> print
    // -----------------------------------------------------------------------
    std::atomic<std::uint64_t> frameCount{0};

    kinematics.registerCommandCallback([&](const ActuatorCommand& cmd) {
        const auto& t = cmd.actuator_targets;
        std::printf("  servos=[%5.1f, %5.1f, %5.1f]  status=%s\n",
                    t[0], t[1], t[2],
                    cmd.status == CommandStatus::Ok ? "OK" : "DEGRADED");
    });

    controller.registerSetpointCallback([&](const PlatformSetpoint& sp) {
        std::printf("  tilt=%+6.3f rad  pan=%+6.3f rad  ->",
                    sp.tilt_rad, sp.pan_rad);
        kinematics.onSetpoint(sp);
    });

    tracker.registerEstimateCallback([&](const SunEstimate& est) {
        std::printf("[frame %4llu] sun=(%6.1f, %6.1f) conf=%.2f  ->",
                    static_cast<unsigned long long>(est.frame_id),
                    est.cx, est.cy, est.confidence);
        controller.onEstimate(est);
    });

    camera.registerFrameCallback([&](const FrameEvent& frame) {
        frameCount.fetch_add(1, std::memory_order_relaxed);
        tracker.onFrame(frame);
    });

    // -----------------------------------------------------------------------
    // 7. Establish a signalfd shutdown path.
    //    The process blocks in read() below until SIGINT or SIGTERM arrives,
    //    then stops the camera and exits cleanly. No sleep or busy-wait is used.
    // -----------------------------------------------------------------------
    sigset_t mask;
    sigemptyset(&mask);
    sigaddset(&mask, SIGINT);
    sigaddset(&mask, SIGQUIT);
    sigaddset(&mask, SIGHUP);
    sigaddset(&mask, SIGTERM);
    sigprocmask(SIG_BLOCK, &mask, nullptr);

    const int sfd = signalfd(-1, &mask, SFD_CLOEXEC);
    if (sfd < 0) {
        std::puts("ERROR: signalfd failed.");
        return 1;
    }

    // -----------------------------------------------------------------------
    // 8. Start and run until a termination signal is received.
    // -----------------------------------------------------------------------
    std::puts("=== Solar Stewart Tracker - Pipeline Demo ===");
    std::puts("Press Ctrl+C to stop.\n");

    if (!camera.start()) {
        std::puts("ERROR: failed to start simulated camera.");
        ::close(sfd);
        return 1;
    }

    // Block here until SIGINT, SIGQUIT, SIGHUP, or SIGTERM.
    signalfd_siginfo fdsi{};
    const ssize_t n = ::read(sfd, &fdsi, sizeof(fdsi));
    (void)n;

    camera.stop();
    ::close(sfd);

    std::puts("\n=== Demo stopped ===");
    std::printf("Total frames processed: %llu\n",
                static_cast<unsigned long long>(frameCount.load()));

    return 0;
}

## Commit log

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2026-03-05 feat(system): add SystemManager interface for core pipeline orchestration
    Introduce SystemManager.hpp defining the top-level coordinator of the
    solar tracker pipeline. Manages system state, event flow, and interaction
    between camera, tracking, control, kinematics, and actuator modules.
2026-03-05 feat(system): implement SystemManager event-driven pipeline
    Add implementation of SystemManager coordinating the realtime
    processing pipeline. Handles frame events, runs tracking →
    control → kinematics, and dispatches actuator commands while
    managing system states and latency tracking.
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2026-03-05 Feature #3: Add Kinematics3RRS interface for 3RRS parallel mechanism IK solver
    Defines the Kinematics3RRS class with Config struct containing geometry
    parameters (base/platform radius, horn/rod lengths), servo mapping
    (neutral angles, direction), and layout angles for all three legs.
    Exposes onSetpoint() receiving PlatformSetpoint (pitch/roll in radians)
    and fires ActuatorCommand (servo degrees 0-180) via registered callback.
2026-03-05 Feature #3: Implement 3RRS inverse kinematics solver
    Computes per-leg servo angles using rotation matrix Ry(pitch)*Rx(roll).
    Each leg resolves two IK branches; chooseClosest() selects the branch
    nearest to the previous solution for motion continuity. otherBranch()
    handles forward-facing horn constraint (cos(q) < 0 guard). Output is
    clamped to [0, 180] degrees and rounded to integer. Falls back to last
    valid output on invalid geometry config.
2026-03-05 Feature #3: Add lightweight test framework macros (test_common.hpp)
    Provides TEST(), REQUIRE(), and REQUIRE_NEAR() macros used across
    unit tests. Uses a static registration pattern to collect and run
    named test cases without external dependencies.
2026-03-05 Feature #3: Add unit tests for Kinematics3RRS IK solver
    Three test cases:
    1. Outputs are finite, within [0,180] deg, and integer-valued after lround().
    2. Small input changes produce small output changes (continuity check, <= 10 deg delta).
    3. Invalid geometry config (horn_length=0) falls back to servo neutral angles
    instead of producing NaN or out-of-range values.
2026-03-05 Add PCA9685 16-channel PWM controller driver - Implement core driver for PCA9685 I2C PWM controller - Add support for raw PWM count configuration and servo-style pulse width (µs) - Include configurat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
2026-03-05 implement PCA9685 PWM driver functionality Add full implementation of PCA9685 I2C PWM controller including: - Initialization with configurable mode registers (MODE1/MODE2) - PWM frequency setting (pr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
2026-03-05 implement ServoDriver for Stewart platform servos
    - Add high-level ServoDriver class to convert servo angles (degrees) to calibrated PWM pulses
    - Support PCA9685 hardware driver with log-only fallback for non-Linux environments
    - Include per-channel calibration (min/max pulse/angle, inversion, neutral park positions)
    - Add start/stop/park functionality and deterministic apply() for actuator commands
2026-03-05 Implement ServoDriver for PCA9685 servo control - Add core logic to convert servo degrees to pulse width (us) - Implement park_all() for safe servo neutral positioning - Add Linux I2C support with lo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
2026-03-05 Add II2CDevice interface for I2C register communication Add platform-agnostic II2CDevice interface defining core register-level I2C read/write primitives (u8 single register, multi-byte read/write). 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
2026-03-05 add LinuxI2CDevice implementation for I2C bus access Add Linux-specific I2C device class implementing the II2CDevice interface, supporting 7-bit slave address targeting and basic register read/write 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
2026-03-05 Add Linux-specific I2C device class implementing the II2CDevice interface, supporting 7-bit slave address targeting and basic register read/write operations.
2026-03-05 implement LinuxI2CDevice for /dev/i2c-* device nodes - Add LinuxI2CDevice.hpp with class definition inheriting from II2CDevice - Support construction with /dev/i2c-X path and 7-bit I2C slave address 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
2026-03-05 Implement unit tests for PCA9685 using FakeI2CDevice to validate register write behavior for initialization, PWM channel configuration, and pulse duration conversion.
2026-03-05 Add park and clamp validation tests Verify ServoDriver parks all channels to neutral on start when enabled Test degree clamping + inverted channel PWM output ordering Validate PCA9685 channel write b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
2026-03-05 feat(controller): introduce solar tracking controller
    Event-driven controller that converts SunEstimate to PlatformSetpoint
    using proportional gains, deadband, and output clamping. Supports
    thread-safe callback delivery and configurable control parameters.
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2026-03-11 Add SimulatedPublisher interface implementing ICamera for simulation and testing. Provides configurable synthetic frame generation with optional moving spot and Gaussian noise, plus threaded event-dr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
2026-03-11 Add implementation of SimulatedPublisher for development and testing. Produces synthetic frame events with configurable resolution, FPS, moving-spot motion, and Gaussian noise while using timer-based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
2026-03-12 feat: Add motion and static platform models
    [The motion platform above.SLDPRT, The static platform below.SLDPRT]
2026-03-12 feat: Add servo motor and dual-axis servo assembly
    [3230 Servo Motor.SLDPRT, Double-axis narrow U bracket.SLDPRT, Double-axis wide U bracket.SLDPRT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]
2026-03-12 feat: Add linkage arms and ball joint components
    [L1 arm.SLDPRT, L2 arm.SLDPRT, ball head neck.SLDPRT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]
2026-03-12 feat: Add steering wheel components for real and imaginary axes
    [Imaginary axis steering wheel.SLDPRT, Real-axis steering wheel.SLDPRT]
2026-03-12 feat: Add Raspberry Pi enclosure design
    [Raspberry Pi box sketch version.SLDPRT]
2026-03-12 feat: Add fasteners and connector components
    [I M6.SLDPRT, sc-16-yp.SLDPRT]
2026-03-12 feat: Add main assembly model
    [di.SLDASM]
2026-03-12 refactor: Move 3rrs models to diagrams/mechanical model directory
    [3230 Servo Motor.SLDPRT, Double-axis narrow U bracket.SLDPRT, Double-axis wide U bracket.SLDPRT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]
2026-03-12 feat: Add updated BOM with fish-eye joint specifications
    [BOM_updated .xls]
2026-03-12 chore: remove BOM_updated spreadsheet
    [BOM_updated .xls]
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2026-03-13 Add unit tests for ThreadSafeQueue covering core queue semantics. Verifies FIFO ordering, bounded queue behaviour for strict and latest-push modes, blocking wait_pop wake-up, and correct stop handlin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
2026-03-13 Add lightweight custom test runner for unit test execution. Provides a simple registry-based framework to register tests, run the full suite or a single named test, list available tests, and report p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
2026-03-13 Add test build targets and CTest registration for the unit test suite. Defines shared test framework sources, builds separate executables for core, PCA9685, and ServoDriver tests, keeps the hardware 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
2026-03-13 implement LatencyMonitor for pipeline latency measurement Track timestamps for capture, estimate, control, and actuate stages, compute per-stage and total latency, and report statistics including avg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
2026-03-15 test: add robustness tests for LatencyMonitor Add unit tests covering several LatencyMonitor behaviors: - ordered timestamp flow (capture → estimate → control → actuate) - out-of-order event handling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
2026-03-15 docs: add realtime latency measurement report
    Add documentation presenting empirical latency measurements
    for the Solar Stewart Tracker pipeline. Includes end-to-end
    latency statistics, jitter analysis, timestamp strategy, and
    architectural justification for realtime responsiveness.
2026-03-15 docs: add realtime architecture and latency analysis Document the event-driven multi-threaded pipeline used by the Solar Stewart Tracker and provide quantitative latency measurements collected on Ras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
2026-03-21 simplify and tighten the public system orchestration interface.
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2026-03-21 strengthen state-machine coverage for final transitions and control flow.
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2026-03-22 redesign ServoDriver interface for clearer startup, mode, and calibration behavior
2026-03-22 strengthen Linux I2C access with better robustness and error handling.
2026-03-22 expand ServoDriver coverage for startup policy, failover, and runtime modes.
2026-03-23 replace BOM document with corrected and readable version from working branch
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2026-04-07 fix(kinematics): add ik_mtx_ for thread safety, document ZYX Euler rotation convention with reference
2026-04-07 feat(sensors): add ADS1115ManualInput — ALERT/RDY GPIO edge-driven potentiometer input
    Uses libgpiod_event_demo blocking edge callback pattern. Configures PGA
    to ±4.096V to cover full 3.3V pot range. Dr Porr's rpi_ads1115 submodule
    was evaluated but hardcodes PGA to ±2.048V which clips at 62% pot travel.
    Project-native driver resolves this without modifying upstream source.
2026-04-07 feat(sensors): add Mpu6050Publisher — GPIO data-ready edge driven IMU acquisition
    Supports both MPU-6050 (WHO_AM_I=0x68) and ICM-20600 (WHO_AM_I=0x70).
    Physical rig uses ICM-20600, confirmed via: i2cget -y 1 0x68 0x75 -> 0x70.
    Register constants are internal static constexpr, not exposed in config.
    Startup discard window prevents early noisy samples reaching callbacks.
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2026-04-16 fix(camera): adapt to libcamera2opencv API change, add ISP stride compensation, add turbojpeg link
2026-04-16 test: add end-to-end pipeline tests, queue stress tests, register jitter test
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2026-04-16 docs: fix Trixie/Bookworm, state machine manual line, add thread table, update test docs
2026-04-16 docs(diagrams): add Fritzing source and updated circuit diagram
    [circuit_diagram.fzz]
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

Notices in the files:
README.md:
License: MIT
